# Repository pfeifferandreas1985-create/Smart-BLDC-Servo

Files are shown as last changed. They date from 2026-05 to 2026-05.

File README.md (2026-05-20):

# Smart BLDC Servo

Ein intelligenter, kompakter Closed-Loop BLDC-Servo-Controller basierend auf:
- **ESP32-C3 Super Mini**
- **SimpleFOC Mini v1.0 (DRV8313)**
- **AS5600 Magnet-Encoder** (I2C)
- **Feetech STS/SCS Emulation** (Half-Duplex 1-Wire UART, 1 Mbps)

Dieses Projekt ist die Weiterentwicklung des `SmartServoStepperV2` und ersetzt den lauten Stepper-Motor durch einen leisen, effizienten Brushless DC (BLDC) Motor (z. B. Gimbal Motoren).

---

## 🛠 Aktueller Entwicklungsstand

Die Hardware-Dokumentation (Schaltplan-Review, detaillierter Verdrahtungsplan, BOM) ist in den Markdown-Dateien `01` bis `06` im Hauptverzeichnis ausführlich dokumentiert.

### Open-Loop Test Tool (NEU!)
Im Verzeichnis `software/OpenLoopTest/` befindet sich das erste Testprogramm. Dieses Tool dient dazu, die grundlegende Hardware (ESP32-C3 + DRV8313 Treiber + BLDC Motor) sicher zu testen, **bevor** Encoder oder Feetech-Bus angeschlossen werden.

**Funktionen des Test-Tools:**
1. **WLAN-Web-Dashboard:** Steuerung des Motors über eine dunkle, professionelle Web-Oberfläche.
2. **Sicherer Open-Loop Modus:** Der Motor läuft im `velocity_openloop` Modus von SimpleFOC. Das Spannungs-Limit ist extrem konservativ gesetzt (2.5V), damit auch Motoren mit niedrigem Widerstand beim "Blockieren" nicht überhitzen.
3. **Hardware-Schutz:** Der Fehler-Pin (`nFLT`) des DRV8313 wird aktiv in Echtzeit vom ESP32-C3 überwacht. Bei Überstrom/Übertemperatur schaltet der ESP32 den Treiber sofort ab.
4. **Alignment:** Beim Start führt der Code automatisch ein elektrisches Alignment (2 rad/s) aus.

**Nutzung:**
1. Öffnen Sie `OpenLoopTest.ino` in der Arduino IDE und flashen Sie es auf den ESP32-C3 (Achtung: `USB CDC On Boot` muss auf `Enabled` stehen!).
2. Verbinden Sie sich mit dem ESP32 über Ihr Netzwerk.
3. Öffnen Sie `software/OpenLoopTest/gui/index.html` lokal im Browser.
4. Geben Sie die IP des ESP32 ein, klicken Sie auf *MOTOR AKTIVIEREN* und regeln Sie die Geschwindigkeit über den Slider.

---

## 🗂 Verzeichnisstruktur

- `software/` - Enthält Firmware (wie z.B. das OpenLoopTest-Tool)
- `software/OpenLoopTest/gui/` - Web-Dashboard für das Test-Tool
- `01_...` bis `06_...` - Ausführliche Baudokumentationen und Pin-Mappings
- `*.kicad_*` - Die KiCad 10.0 Projektdateien für das Hardware-Design

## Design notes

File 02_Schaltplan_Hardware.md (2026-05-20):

# 02. Hardware & Schaltplan

Dieses Dokument beschreibt die Verkabelung und die essenziellen Passivbauteile (Schutzschaltungen) für den stabilen Betrieb des BLDC 2208 80T am Simple FOC Mini v1.0.

## 1. Schutzschaltungen & Passivbauteile (Hardening)

Um einen zuverlässigen Dauerbetrieb zu gewährleisten und die Hardware vor Spannungsspitzen, Signalfehlern und Boot-Konflikten zu schützen, sind folgende Komponenten zwingend erforderlich:

### 1.1 VMOT Flyback- & Überspannungsschutz
BLDC Motoren können bei abruptem Abbremsen oder Blockieren als Generator wirken und hohe Spannungsspitzen ins Netz zurückspeisen.
*   **Bauteile:** 1x 1000 µF Elektrolytkondensator (Low ESR) + 1x 0.1 µF Keramikkondensator + 1x TVS-Diode **SMBJ24A** (bei 12V-24V) oder **SMBJ15A** (bei 12V) (alle parallel).
*   **Position:** Zwischen `VMOT` (Spannungseingang am Simple FOC Mini) und `GND`. So nah wie möglich an den Strom-Eingangspins des Treiber-Boards platzieren.

### 1.2 Glättung & MCU-Pufferung (Gegen Brownouts)
Verhindert, dass der ESP32-C3 durch Spannungseinbrüche während hoher Motorlasten abstürzt (Resets).
*   **Bauteile (5V Schiene):** 1x 100 µF Elko + 1x 47 µF Keramikkondensator (X7R, 1206, ≥16V) + 1x 100 nF Keramikkondensator.
*   **Position:** Direkt am 5V-Eingangspin des ESP32-C3 Super Mini.
*   **AS5600 Puffer:** 1x 10 µF Keramikkondensator nahe am VCC/GND-Pin des AS5600.
*   **Step-Down Puffer:** 1x 22 µF Keramikkondensator am Ausgang des MP1584EN.

### 1.3 I²C Pull-Up Widerstände (Für stabile 400 kHz)
Der AS5600 benötigt definierte HIGH-Pegel für saubere I2C-Kommunikation. Die internen Pull-Ups des ESP32-C3 sind zu schwach.
*   **Bauteile:** 2x 4.7 kΩ Widerstände.
*   **Position:** Einer von `SDA` an `3.3V` und einer von `SCL` an `3.3V`.

### 1.4 Boot-Safe Pull-Down am Enable Pin
Verhindert, dass der Motor unkontrolliert anläuft, während der ESP32-C3 bootet und die Pins noch im undefinierten Zustand (Floating) sind.
*   **Bauteil:** 1x 10 kΩ Widerstand.
*   **Position:** Zwischen `EN` (Enable-Pin des Simple FOC, Active-HIGH) und `GND`. Hält den Treiber deaktiviert, bis der ESP den Pin bewusst auf HIGH zieht.

### 1.5 nSLP & nRST Aktivierungs-Pull-Ups
*   **Problem:** Der DRV8313 besitzt interne 100kΩ Pull-Downs. Bleiben `nSLP` und `nRST` unbeschaltet, bleibt der Chip im Sleep/Reset-Zustand.
*   **Bauteile:** 2x 10 kΩ Widerstände.
*   **Position:** Von `nSLP` gegen `3.3V` und von `nRST` gegen `3.3V` (zieht die Pins dauerhaft HIGH und aktiviert den Treiber).

### 1.6 nFLT Fault-Feedback
*   **Bauteil:** 1x 10 kΩ Widerstand.
*   **Position:** Von `nFLT` (Fault-Ausgang des Simple FOC, Open-Drain) gegen `3.3V`. Der Pin wird an `GPIO 4` des ESP32-C3 angeschlossen, um Treiberfehler (Überstrom/Übertemperatur) in der Firmware abzufangen.

### 1.7 Split-Path Level Shifter für Feetech-Bus (1 Mbps Stabilität)
Verhindert Signalverrundungen und Frame-Fehler bei hohen Baudraten (1 Mbps), indem Sende- und Empfangspfad auf der 3.3V-Seite getrennt bleiben.
*   **Bauteile:** 1x BSS138 MOSFET (für TX) + 1x Spannungsteiler (4.7 kΩ Serie, 10 kΩ gegen GND, für RX) + 1x 2.2 kΩ Pull-Up (Terminierung).
*   **Position:**
    *   **TX-Pfad:** ESP32 TX (`GPIO 21`) → Gate/Source des BSS138 (Pegelwandlung 3.3V → 5V) → 5V Feetech Bus.
    *   **RX-Pfad:** 5V Feetech Bus → Spannungsteiler (4.7 kΩ / 10 kΩ) → ESP32 RX (`GPIO 20`).
    *   **Terminierung:** 2.2 kΩ Pull-Up von der 5V Feetech-Datenleitung gegen 5V.

---

## 2. Pin-Belegung & Architektur

### ESP32-C3 Super Mini Pinout:
*   **5V & GND:** Logikstromversorgung vom MP1584EN (mit 100µF + 47µF + 100nF Pufferung).
*   **3.3V & GND:** Sensorstromversorgung (AS5600) und Referenz für Level Shifter LV.
*   **GPIO 0 (PWM A):** Simple FOC IN1.
*   **GPIO 1 (PWM B):** Simple FOC IN2.
*   **GPIO 2 (PWM C):** Simple FOC IN3.
*   **GPIO 3 (EN):** Simple FOC Enable (mit 10kΩ Pull-Down an GND).
*   **GPIO 4 (nFLT):** Simple FOC Fault-Eingang (mit 10kΩ Pull-Up an 3.3V).
*   **GPIO 8 (SDA):** AS5600 SDA (mit 4.7kΩ Pull-Up an 3.3V).
*   **GPIO 9 (SCL):** AS5600 SCL (mit 4.7kΩ Pull-Up an 3.3V).
*   **GPIO 20 (RX):** Feetech Bus Empfang (über 4.7kΩ / 10kΩ Spannungsteiler von 5V Bus).
*   **GPIO 21 (TX):** Feetech Bus Senden (über unidirectional BSS138 Level Shifter auf 5V Bus).

### Stromversorgung (Power Routing)
1. **12V Hauptnetzteil:** Geht an Simple FOC Mini (VMOT/GND) und an den MP1584EN Step-Down (Eingang).
2. **MP1584EN Step-Down:** Wandelt 12V auf exakt **5.0V** um (Ausgang lokal mit 22µF gepuffert).
3. **5V Rail:** Versorgt den Level Shifter (HV-Referenz/Bus-Terminierung) und den 5V Eingang des ESP32-C3 Super Mini.
4. **3.3V Rail:** Vom ESP32-C3 3.3V Pin an den AS5600 Sensor und als Pull-Up-Referenz für nSLP, nRST und nFLT.

---

## 3. Logischer Schaltplan (Mermaid)

```mermaid
graph TD
    %% Stromversorgung
    PSU((12V Netzteil)) -->|12V| TVS[TVS SMBJ24A + 1000µF + 0.1µF]
    TVS -->|Gepufferte 12V| FOC[Simple FOC Mini]
    PSU -->|12V| BUCK[MP1584 Step-Down]
    BUCK -->|5V + 22µF| ESP_P_BUFF[100µF + 47µF + 100nF Puffer]
    ESP_P_BUFF -->|5V Logik| ESP_5V[ESP32-C3 5V Input]
    BUCK -->|5V| SHIFTER_HV[Terminierung 2.2kΩ an 5V Bus]
    
    %% Logikspannung
    ESP_5V -->|ESP Intern| ESP3V3(ESP32 3.3V Pin)
    ESP3V3 -->|3.3V| AS5600[AS5600 Encoder + 10µF]
    ESP3V3 -->|3.3V Pullups| PU_CTRL[Pull-Ups für nSLP, nRST & nFLT]
    
    %% Treiber Aktivierung & Fault
    PU_CTRL -->|10kΩ an 3.3V| FOC_nSLP[nSLP Pin]
    PU_CTRL -->|10kΩ an 3.3V| FOC_nRST[nRST Pin]
    FOC_nFLT[nFLT Pin] -->|Fault Signal| ESP_GPIO4[GPIO 4 - nFLT]
    PU_CTRL -->|10kΩ an 3.3V| ESP_GPIO4
    
    %% Boot-Safe Enable
    PD_EN[10kΩ Pull-Down an GND] --- ESP_GPIO3[GPIO 3 - EN]
    ESP_GPIO3 -->|Enable Signal| FOC
    
    %% PWM Signale
    ESP_GPIO0[GPIO 0] -->|PWM A| FOC
    ESP_GPIO1[GPIO 1] -->|PWM B| FOC
    ESP_GPIO2[GPIO 2] -->|PWM C| FOC
    
    %% I2C mit Pullups
    PU_I2C[2x 4.7kΩ an 3.3V] --- I2C_BUS[SDA/SCL Bus]
    ESP_GPIO8_9[GPIO 8/9] --> I2C_BUS
    I2C_BUS --> AS5600
    
    %% Motor
    FOC -->|3-Phasen AC| MOTOR((BLDC 2208 80T))
    AS5600 -.->|Magnetfeld| MOTOR
    
    %% Feetech Kommunikation Split-Path
    ESP_TX[GPIO 21 TX] -->|3.3V TX| LS_TX[BSS138 Level Shifter 3.3V-5V]
    LS_TX -->|5V TX| FT_BUS((5V Feetech Datenbus))
    FT_BUS -->|5V RX| DIV_RX[Spannungsteiler 4.7kΩ / 10kΩ]
    DIV_RX -->|3.3V RX| ESP_RX[GPIO 20 RX]
```

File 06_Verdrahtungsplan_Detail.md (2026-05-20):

# SmartBLDCServo – Detaillierter Verdrahtungsplan

> Dieser Plan beschreibt **jede einzelne Verbindung** zwischen den Modulen
> und erklärt exakt, wo jeder Widerstand, Kondensator und die Schutzdiode
> angeschlossen werden muss.

---

## Übersicht der Module (werden NICHT verändert)

| Ref  | Modul | Funktion |
|---|---|---|
| U1 | ESP32-C3 Super Mini | Mikrocontroller (MCU) |
| U2 | SimpleFOC Mini v1.0 | BLDC-Motortreiber (DRV8313) |
| U3 | MP1584EN Modul | Step-Down 12V → 5V |
| U4 | BOB-12009 (BSS138 Board) | Level Shifter 3.3V ↔ 5V |
| J1 | Schraubklemme 2-pol | 12V Eingang (VMOT + GND) |
| J2 | JST-XH 3-pol | Feetech-Bus (5V, DATA, GND) |
| J3 | JST-XH 4-pol | AS5600 Encoder (VCC,GND,SDA,SCL)|

---

## Übersicht aller passiven Bauteile

| Ref | Typ | Wert | Funktion | Angeschlossen zwischen |
|---|---|---|---|---|
| D1 | TVS-Diode | SMBJ15A | Überspannungsschutz 12V | VMOT (Kathode) ↔ GND (Anode) |
| C1 | Elko | 1000µF/25V | Bulk-Puffer 12V | VMOT ↔ GND |
| C2 | Keramik | 100nF/50V | HF-Entkopplung SimpleFOC | VMOT ↔ GND (direkt am U2) |
| C3 | Keramik | 10µF/25V | Eingangspuffer Buck-Converter | U3 IN+ ↔ U3 IN- |
| C4 | Keramik | 22µF/16V | Ausgangspuffer Buck-Converter | U3 OUT+ ↔ U3 OUT- |
| C5 | Elko | 100µF/10V | MCU-Puffer (Low-ESR) | U1 5V-Pin ↔ GND |
| C6 | Keramik | 47µF/16V | MCU-Puffer (X7R, 1206) | U1 5V-Pin ↔ GND |
| C7 | Keramik | 100nF | MCU HF-Filter | U1 5V-Pin ↔ GND |
| C8 | Keramik | 10µF/10V | AS5600 Entkopplung | J3 Pin1 (VCC) ↔ J3 Pin2 (GND) |
| R1 | 0603 | 10kΩ | EN Pull-Down (Treiber aus bei Boot)| U2 EN ↔ GND |
| R2 | 0603 | 10kΩ | nFLT Pull-Up (Fehlerleitung) | U2 nFLT ↔ 3.3V |
| R3 | 0603 | 10kΩ | nSLP Pull-Up (Treiber aktiv) | U2 nSLP ↔ 3.3V |
| R4 | 0603 | 10kΩ | nRST Pull-Up (kein Reset) | U2 nRST ↔ 3.3V |
| R5 | 0603 | 4.7kΩ | I2C SDA Pull-Up | SDA-Leitung ↔ 3.3V |
| R6 | 0603 | 4.7kΩ | I2C SCL Pull-Up | SCL-Leitung ↔ 3.3V |
| R7 | 0603 | 220Ω | TX Serienwiderstand (BOB-12009) | U1 GPIO21 ↔ U4 LV1 |
| R8 | 0603 | 4.7kΩ | RX Spannungsteiler (Serie) | TTL_1_Wire ↔ U1 GPIO20 |
| R9 | 0603 | 10kΩ | RX Spannungsteiler (Pull-Down) | U1 GPIO20 ↔ GND |
| R10 | 0603 | 2.2kΩ | Bus-Terminierung Pull-Up | TTL_1_Wire ↔ 5V |

---

## TEIL 1: STROMVERSORGUNG

### 1.1 – 12V Eingang und Schutz

```
       J1 (Schraubklemme)
       ┌──────┐
  12V──┤ Pin1 ├──┬──────────────────────────┬──── VMOT-Schiene
       │      │  │                          │
  GND──┤ Pin2 ├──┼──────────────────────────┼──── GND-Schiene
       └──────┘  │                          │
                 │                          │
           ┌─────┴─────┐            ┌───────┴───────┐
           │    D1      │            │     C1        │
           │  SMBJ15A   │            │  1000µF/25V   │
           │  (TVS)     │            │  (Elko)       │
           │            │            │               │
           │ Kathode=VMOT│           │  (+) = VMOT   │
           │ Anode=GND  │            │  (-) = GND    │
           └─────┬─────┘            └───────┬───────┘
                 │                          │
                 └──────────GND─────────────┘
```

**D1 (SMBJ15A):** Direkt parallel an J1. Kathode (Strich-Seite) an 12V/VMOT, Anode an GND.
Zweck: Kappt Spannungsspitzen von regenerativem Motorbremsen.

**C1 (1000µF/25V):** Direkt parallel an J1. Plus an VMOT, Minus an GND.
Zweck: Puffert große Stromspitzen beim Motorstart.

### 1.2 – SimpleFOC Mini Stromversorgung

```
  VMOT-Schiene ───────────────┬──── U2 VCC (Pin 14)
                              │
                         ┌────┴────┐
                         │   C2    │
                         │ 100nF   │
                         │ /50V    │
                         └────┬────┘
                              │
  GND-Schiene ────────────────┴──── U2 GND (Pin 15)
```

**C2 (100nF/50V):** So nah wie möglich an den VCC/GND-Pins des SimpleFOC Mini löten.
Zweck: Filtert hochfrequentes Rauschen des DRV8313 Treibers.

### 1.3 – Buck-Converter (MP1584EN) 12V → 5V

```
  VMOT ──┬──── U3 IN+          U3 OUT+ ──┬──── 5V-Schiene
         │                               │
    ┌────┴────┐                     ┌─────┴────┐
    │   C3    │                     │    C4    │
    │ 10µF    │                     │  22µF    │
    │ /25V    │                     │  /16V    │
    └────┬────┘                     └─────┬────┘
         │                               │
  GND ───┴──── U3 IN-          U3 OUT- ──┴──── GND
```

**C3 (10µF):** Direkt an IN+/IN- des MP1584EN Moduls.
**C4 (22µF):** Direkt an OUT+/OUT- des MP1584EN Moduls.

### 1.4 – ESP32-C3 Spannungsversorgung (5V-Eingang)

```
  5V-Schiene ──┬───────────────────────── U1 Pin "5V" (Pin 8)
               │
          ┌────┴────┐  ┌────┴────┐  ┌────┴────┐
          │   C5    │  │   C6    │  │   C7    │
          │ 100µF   │  │  47µF   │  │ 100nF   │
          │ Elko    │  │ Keramik │  │ Keramik │
          │ /10V    │  │ /16V    │  │         │
          └────┬────┘  └────┬────┘  └────┬────┘
               │            │            │
  GND ─────────┴────────────┴────────────┘
```

**C5, C6, C7:** Alle drei parallel, direkt am 5V-Pin des ESP32-C3 gegen GND.
Zweck: Verhindert MCU-Brownouts bei WiFi/BLE-Spitzenstrom.

### 1.5 – 3.3V Logik (vom ESP32 LDO)

```
  U1 Pin "3V3" (Pin 6) ───── 3.3V-Schiene
                               │
                               ├── R2, R3, R4 (Pull-Ups)
                               ├── R5, R6 (I2C Pull-Ups)
                               ├── U4 LV (BOB-12009 Low-Side)
                               └── J3 Pin1 (AS5600 VCC)
```

**WICHTIG:** Der 3.3V-Ausgang am SimpleFOC Mini (Pin 2) bleibt **UNBESCHALTET!**

---

## TEIL 2: ESP32-C3 ↔ SimpleFOC Mini (Motorsteuerung)

### 2.1 – PWM-Signale (direkte Verbindungen, KEINE Widerstände)

```
  U1 GPIO 0 ─────────────────── U2 IN1  (Phase A)
  U1 GPIO 1 ─────────────────── U2 IN2  (Phase B)
  U1 GPIO 2 ─────────────────── U2 IN3  (Phase C)
```

### 2.2 – Enable mit Pull-Down (R1)

```
  U1 GPIO 3 ──────┬──────────── U2 EN
                   │
              ┌────┴────┐
              │   R1    │
              │  10kΩ   │
              └────┬────┘
                   │
                  GND
```

**R1 (10kΩ):** Ein Bein an die Leitung GPIO3↔EN, anderes Bein an GND.
Zweck: Hält den Motortreiber während des ESP32-Bootvorgangs DEAKTIVIERT.

### 2.3 – Fault-Pin mit Pull-Up (R2)

```
                  3.3V
                   │
              ┌────┴────┐
              │   R2    │
              │  10kΩ   │
              └────┬────┘
                   │
  U1 GPIO 4 ──────┴──────────── U2 nFLT
```

**R2 (10kΩ):** Ein Bein an die Leitung GPIO4↔nFLT, anderes Bein an 3.3V.
Zweck: nFLT ist Open-Drain. Pull-Up hält Signal auf HIGH wenn kein Fehler vorliegt.

### 2.4 – Sleep und Reset permanent aktiv (R3, R4)

```
                  3.3V                3.3V
                   │                   │
              ┌────┴────┐         ┌────┴────┐
              │   R3    │         │   R4    │
              │  10kΩ   │         │  10kΩ   │
              └────┬────┘         └────┬────┘
                   │                   │
              U2 nSLP              U2 nRST
```

**R3 (10kΩ):** Von U2 nSLP (Pin 8) nach 3.3V. Treiber bleibt aus Sleep-Modus.
**R4 (10kΩ):** Von U2 nRST (Pin 6) nach 3.3V. Treiber bleibt aus Reset.

> **ACHTUNG:** nSLP und nRST haben interne 100kΩ Pull-Downs im DRV8313!
> Ohne diese externen 10kΩ Pull-Ups bleibt der Treiber im Schlaf/Reset!

---

## TEIL 3: ESP32-C3 ↔ AS5600 Encoder (I2C über J3)

### 3.1 – Encoder-Steckerbelegung (J3, JST-XH 4-pol)

```
       J3 (4-pol Buchse)
       ┌──────────┐
  VCC──┤  Pin 1   ├──── 3.3V (vom ESP32 LDO)
  GND──┤  Pin 2   ├──── GND
  SDA──┤  Pin 3   ├──── U1 GPIO 8
  SCL──┤  Pin 4   ├──── U1 GPIO 9
       └──────────┘
```

### 3.2 – I2C Pull-Ups (R5, R6) und Entkopplung (C8)

```
         3.3V         3.3V
          │             │
     ┌────┴────┐   ┌────┴────┐
     │   R5    │   │   R6    │
     │  4.7kΩ  │   │  4.7kΩ  │
     └────┬────┘   └────┬────┘
          │             │
  GPIO8 ──┴── SDA       │
                        │
  GPIO9 ────────────────┴── SCL

  J3 Pin1 (VCC) ──┬──── 3.3V
                   │
              ┌────┴────┐
              │   C8    │
              │  10µF   │
              └────┬────┘
                   │
  J3 Pin2 (GND) ──┴──── GND
```

**R5 (4.7kΩ):** Ein Bein an SDA-Leitung (GPIO8 ↔ J3 Pin3), anderes an 3.3V.
**R6 (4.7kΩ):** Ein Bein an SCL-Leitung (GPIO9 ↔ J3 Pin4), anderes an 3.3V.
**C8 (10µF):** Direkt an J3 zwischen Pin1 (VCC) und Pin2 (GND). So nah wie möglich am Stecker.

---

## TEIL 4: FEETECH-BUS (1 Mbps, Split-Path über BOB-12009)

### 4.1 – Gesamtübersicht

```
  3.3V-Seite (ESP32)              5V-Seite (Bus)
  ══════════════════              ═══════════════

  GPIO21 (TX)──[R7 220Ω]──U4 LV1 ── U4 HV1──┬── TTL_1_Wire
                                              │
  GPIO20 (RX)──────────────[R8 4.7kΩ]────────┤
       │                                      │
      [R9 10kΩ]                          [R10 2.2kΩ]
       │                                      │
      GND                                    5V

  U4 LV  = 3.3V
  U4 HV  = 5V
  U4 GND = GND
```

### 4.2 – TX-Pfad: ESP32 → Bus (über BOB-12009 Kanal 1)

```
  U1 GPIO 21 ──[R7 220Ω]──── U4 LV1
                              U4 HV1 ──── TTL_1_Wire (Datenleitung)
```

**R7 (220Ω):** In Serie zwischen GPIO21 und dem LV1-Pin des BOB-12009.
Zweck: Begrenzt Strom und reduziert Überschwinger an der steigenden Flanke.

### 4.3 – RX-Pfad: Bus → ESP32 (Spannungsteiler, NICHT über BOB-12009)

```
  TTL_1_Wire (5V Bus) ──[R8 4.7kΩ]──┬──── U1 GPIO 20
                                      │
                                 [R9 10kΩ]
                                      │
                                     GND
```

**R8 (4.7kΩ):** Von TTL_1_Wire Busleitung zum GPIO20 (in Serie).
**R9 (10kΩ):** Von GPIO20 nach GND (Pull-Down).

Ergebnis: 5V × (10k / (4.7k + 10k)) = **3.4V** → sicher für den 3.3V-toleranten GPIO.
Zweck: Schneller, passiver Pegelwandler ohne MOSFET-Verzögerung für RX.

### 4.4 – Bus-Terminierung (R10)

```
  TTL_1_Wire ──[R10 2.2kΩ]──── 5V (von MP1584EN)
```

**R10 (2.2kΩ):** Direkt am Feetech-Stecker J2, von der Datenleitung nach 5V.
Zweck: Zieht die Busleitung schnell auf 5V zurück (scharfe steigende Flanken bei 1 Mbps).

### 4.5 – BOB-12009 Versorgung und unbeschaltete Pins

```
  U4 LV  ──── 3.3V (vom ESP32)
  U4 HV  ──── 5V (vom MP1584EN)
  U4 GND ──── GND
  U4 LV2 ──── unbeschaltet (offen)
  U4 LV3 ──── unbeschaltet (offen)
  U4 LV4 ──── unbeschaltet (offen)
  U4 HV2 ──── unbeschaltet (offen)
  U4 HV3 ──── unbeschaltet (offen)
  U4 HV4 ──── unbeschaltet (offen)
```

### 4.6 – Feetech-Stecker (J2, JST-XH 3-pol)

```
       J2 (3-pol Buchse)
       ┌──────────┐
   5V──┤  Pin 1   ├──── 5V (Versorgung für externe Servos)
  DATA──┤  Pin 2   ├──── TTL_1_Wire (Datenleitung)
  GND──┤  Pin 3   ├──── GND
       └──────────┘
```

---

## TEIL 5: MOTOR-AUSGÄNGE (SimpleFOC Mini → Motor)

Die drei Phasenausgänge des SimpleFOC Mini gehen direkt zum BLDC-Motor:

```
  U2 OUT1 (Pin 13) ──── Motor Phase A
  U2 OUT2 (Pin 12) ──── Motor Phase B
  U2 OUT3 (Pin 11) ──── Motor Phase C
```

Keine zusätzlichen Bauteile notwendig. Die Motorleitungen sollten möglichst
kurz und mit breiten Leiterbahnen (≥1.5mm) geführt werden.

---

## ZUSAMMENFASSUNG: Alle Verbindungen auf einen Blick

### ESP32-C3 Pin-Belegung (U1)

| ESP32 Pin | Richtung | Verbindung zu | Passive Bauteile |
|---|---|---|---|
| 5V | Eingang  | MP1584EN OUT+ | C5 (100µF), C6 (47µF), C7 (100nF) → GND |
| 3V3 | Ausgang  | 3.3V-Schiene | – |
| GND | – | System-GND | – |
| GPIO 0 | Ausgang  | U2 IN1 | – |
| GPIO 1 | Ausgang  | U2 IN2 | – |
| GPIO 2 | Ausgang  | U2 IN3 | – |
| GPIO 3 | Ausgang  | U2 EN | R1 (10kΩ) → GND |
| GPIO 4 | Eingang  | U2 nFLT | R2 (10kΩ) → 3.3V |
| GPIO 8 | Bidir. | J3 Pin3 (SDA) | R5 (4.7kΩ) → 3.3V |
| GPIO 9 | Ausgang  | J3 Pin4 (SCL) | R6 (4.7kΩ) → 3.3V |
| GPIO 20 | Eingang  | TTL_1_Wire via R8 | R8 (4.7kΩ Serie), R9 (10kΩ) → GND |
| GPIO 21 | Ausgang  | U4 LV1 via R7 | R7 (220Ω Serie) |

### SimpleFOC Mini Pin-Belegung (U2)

| U2 Pin | Verbindung zu | Passive Bauteile |
|---|---|---|
| VCC (14)  | VMOT (12V-Schiene) | C2 (100nF) → GND |
| GND (15)  | System-GND | – |
| GND1 (1)  | System-GND | – |
| GND2 (4)  | System-GND | – |
| IN1 (3) | U1 GPIO 0 | – |
| IN2 (5) | U1 GPIO 1 | – |
| IN3 (7) | U1 GPIO 2 | – |
| EN (9) | U1 GPIO 3 | R1 (10kΩ) → GND |
| nRST (6)  | – | R4 (10kΩ) → 3.3V |
| nSLP (8)  | – | R3 (10kΩ) → 3.3V |
| nFLT (10) | U1 GPIO 4 | R2 (10kΩ) → 3.3V |
| 3.3V (2)  | **UNBESCHALTET!** | – |
| OUT1 (13) | Motor Phase A | – |
| OUT2 (12) | Motor Phase B | – |
| OUT3 (11) | Motor Phase C | – |

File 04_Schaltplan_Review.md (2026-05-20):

# 04. Schaltplan- & Schutzschaltungs-Review (SmartBLDCServo)

Dieses Dokument enthält das technische Review des Schaltplans und der Schutzschaltungen für das Projekt **SmartBLDCServo** auf Basis des Gimbal-Motors (2208 80T) und des **SimpleFOC Mini v1.0**-Treibers. Die Schaltung wurde im Vergleich zu den Freigabestandards des Vorgängerprojekts **SmartServoStepperV2** geprüft.

---

## 1. Kritische Fehler (Müssen vor dem PCB-Layout behoben werden)

### 1.1 Unbeschaltete nSLP und nRST Pins am SimpleFOC Mini (Fehlende Aktivierung)
*   **Problem:** Der DRV8313-Treiberchip auf dem SimpleFOC Mini besitzt interne **100 kΩ Pull-Down-Widerstände** an den Steuereingängen. Die Pins `nSLP` (Sleep, Pin 8) und `nRST` (Reset, Pin 6) sind **Active-LOW**. Wenn diese Pins in der Schaltung unbeschaltet (floating) bleiben, zieht der Chip sie auf GND und verbleibt dauerhaft im Sleep- und Reset-Zustand. Der Treiber wird keine PWM-Signale annehmen und der Motor bleibt stromlos.
*   **Lösung:** Verbinden Sie sowohl `nSLP` als auch `nRST` mit **3.3V** (entweder direkt oder jeweils über einen **10 kΩ Pull-Up-Widerstand**). Dadurch wird der Treiber permanent aktiviert.
*   **Hinweis:** Der `3.3V` Pin auf dem SimpleFOC Mini Header (Pin 2) ist der Ausgang eines chipinternen LDO-Reglers (max. 10 mA). Sie können die Pins `nSLP`/`nRST` entweder mit diesem Pin 2 oder direkt mit der 3.3V-Schiene des ESP32-C3 verbinden (empfohlen, da stabiler).

### 1.2 Fehlende Glättungs- und Pufferkondensatoren an den Logikschienen (5V & 3.3V)
*   **Problem:** In der aktuellen BOM und dem Verdrahtungsplan fehlen jegliche Abblockkondensatoren an den Spannungsreglern und MCU-Eingängen. BLDC-Motoren erzeugen durch das schnelle Schalten der Phasen starke Störungen (Rippel) auf der Versorgungsspannung. Ohne Pufferung wird der ESP32-C3 beim Anlauf des Motors durch Spannungsabfälle (Brownouts) abstürzen oder unvorhersehbares Verhalten zeigen.
*   **Lösung (analog zum SmartServoStepperV2-Standard):**
    *   **MP1584EN Ausgang (5V Rail):** Platzieren Sie mindestens einen **22 µF Keramikkondensator** (X7R, 1206) direkt am Ausgang des Reglers.
    *   **ESP32-C3 5V Input:** Platzieren Sie eine Kombination aus **100 µF Elko** + **47 µF Keramikkondensator** (X7R, 1206, ≥16V) + **100 nF Keramikkondensator** so nah wie möglich am 5V-Pin des ESP32.
    *   **AS5600 Sensor (3.3V Rail):** Platzieren Sie einen **10 µF Keramikkondensator** direkt an den VCC- und GND-Pins des Sensors.

---

## 2. Dringende Empfehlungen zur Stabilitäts-Optimierung

### 2.1 Feetech-Bus Level Shifter: Bidirektional vs. Unidirektionaler Split-Pfad (1 Mbps Stabilität)
*   **Problem:** Die Schaltung sieht den kombinierten 1-Wire UART mit dem bidirektionalen Level Shifter BSS138 (`LV1` zu `HV1` mit 220 Ω Schutzwiderstand) vor. Bei der hohen Übertragungsrate des Feetech-Busses von **1 Mbps** führt die hohe Gate-Kapazität und der langsame Pull-Up-Übergang des BSS138 zu einer starken Verrundung der Signalflanken. Dies führt im Betrieb häufig zu Frame-Fehlern.
*   **Lösung aus SmartServoStepperV2 V1.6:**
    Nutzen Sie die freien GPIOs des ESP32-C3 und teilen Sie den Pfad in einen unidirektionalen TX-Pfad und einen RX-Spannungsteiler-Pfad auf. Diese werden erst auf der 5V-Seite zusammengeführt:
    1.  **TX-Pfad:** ESP32 TX (`GPIO 21`) → Gate/Source des BSS138 (Pegelwandlung 3.3V → 5V) → 5V-Bus.
    2.  **RX-Pfad:** 5V-Bus → Spannungsteiler (**4.7 kΩ** in Serie, **10 kΩ** gegen GND) → ESP32 RX (`GPIO 20`).
    3.  **Terminierung:** Ein starker **2.2 kΩ Pull-Up-Widerstand** vom 5V-Bus gegen 5V sorgt für scharfe Signalflanken.
*   **Vorteil:** Durch diese Trennung muss der Level Shifter nur unidirektional arbeiten, was die Signalqualität bei 1 Mbps massiv erhöht. Da beim ESP32-C3 die GPIOs 4, 5, 6, 7 und 10 ungenutzt sind, steht dieser Änderung nichts im Weg.

### 2.2 Fehlender TVS-Schutz am VMOT-Eingang (Flyback-Überspannungsschutz)
*   **Problem:** Der 1000 µF Elko schützt vor kurzzeitigen Rückspeisungen, fängt jedoch keine hochenergetischen transienten Überspannungen ab, die entstehen, wenn der Motor blockiert oder abrupt gestoppt wird. Diese Spannungsspitzen können den SimpleFOC Mini sowie den MP1584 Buck-Converter zerstören.
*   **Lösung:** Schalten Sie eine **TVS-Diode** (Transienten-Absorptionsdiode) vom Typ **SMBJ24A** (bei 12V-24V Betrieb) oder **SMBJ15A** (bei reinem 12V Betrieb) parallel zum 1000 µF Kondensator direkt an den VMOT-Eingang (Kathode an VMOT, Anode an GND).

---

## 3. Optionale Komfort-Features

### 3.1 Nutzung des Fehler-Pins (nFLT)
*   **Vorteil:** Der SimpleFOC Mini hat einen Open-Drain Ausgang `nFLT` (Pin 10), der im Fehlerfall (Übertemperatur, Überstrom am DRV8313) auf LOW gezogen wird.
*   **Empfehlung:** Verbinden Sie `nFLT` über einen **10 kΩ Pull-Up-Widerstand** gegen 3.3V mit einem freien ESP32 GPIO (z.B. `GPIO 4`). Ihre Firmware kann dadurch Fehler sofort erkennen, den Motor stoppen und eine Fehlermeldung über den Bus senden.

---

## 4. Korrekt und sinnvoll umgesetzte Schaltungsteile (Best Practice)

*   ✔ **Boot-Safe Enable State:** Der **10 kΩ Pull-Down-Widerstand** am `EN`-Pin (Pin 9) des SimpleFOC Mini ist absolut korrekt. Da der Treiber-Enable-Pin Active-HIGH is, hält dieser Widerstand den Motor beim Booten der MCU sicher stromlos, solange die GPIOs schwimmen.
*   ✔ **I2C Pull-Ups:** Die beiden **4.7 kΩ Pull-Up-Widerstände** an SDA/SCL gegen 3.3V sind für den stabilen Betrieb des AS5600 im 400 kHz Fast Mode ideal dimensioniert.
*   ✔ **Softwareseitige Sicherheitslimits:** Die Reduzierung des Spannungslimits im Code (`driver.voltage_limit = 6.0;` bei `driver.voltage_power_supply = 12.0;`) ist sehr sinnvoll für Gimbal-Motoren, da diese einen hohen Phasenwiderstand aufweisen und bei vollen 12V schnell überhitzen würden.

---

## 5. Empfohlenes optimiertes Pin-Mapping

Unter Berücksichtigung der Optimierungen ergibt sich folgende Empfehlung für die Pin-Belegung des ESP32-C3:

| Pin | Funktion | Richtung | Anbindung / Hardware-Schutz |
| :--- | :--- | :--- | :--- |
| **GPIO 0** | PWM Phase A | Ausgang | Direkt an `IN1` des SimpleFOC |
| **GPIO 1** | PWM Phase B | Ausgang | Direkt an `IN2` des SimpleFOC |
| **GPIO 2** | PWM Phase C | Ausgang | Direkt an `IN3` des SimpleFOC |
| **GPIO 3** | Driver Enable | Ausgang | An `EN` des SimpleFOC (mit 10 kΩ Pull-Down an GND) |
| **GPIO 4** | Driver Fault (nFLT)| Eingang | An `nFLT` des SimpleFOC (mit 10 kΩ Pull-Up an 3.3V) |
| **GPIO 8** | I2C SDA | Bidirektional | An AS5600 SDA (mit 4.7 kΩ Pull-Up an 3.3V) |
| **GPIO 9** | I2C SCL | Ausgang | An AS5600 SCL (mit 4.7 kΩ Pull-Up an 3.3V) |
| **GPIO 20**| Feetech Bus RX | Eingang | Über 5V→3.3V Spannungsteiler (4.7 kΩ / 10 kΩ) an den Bus |
| **GPIO 21**| Feetech Bus TX | Ausgang | Über Level Shifter (BSS138) an den 5V-Bus |

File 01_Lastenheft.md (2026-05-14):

# Projekt: Smart BLDC Servo – Lastenheft

## 1. Zielbeschreibung
Entwicklung eines intelligenten, Closed-Loop gesteuerten BLDC-Servos auf Basis eines Gimbal-Motors (2208 80T) und ESP32-C3 Super Mini. Das System integriert einen Simple FOC Mini v1.0 Treiber und einen AS5600 Encoder für präzises Positions-, Geschwindigkeits-, und Drehmoment-Feedback mittels Field Oriented Control (FOC).
Es soll sich am Datenbus exakt wie ein Feetech STS/SCS Servomotor ansprechen lassen.

## 2. Hardware-Spezifikationen
*   **Zentrale Logik:** ESP32-C3 Super Mini.
*   **Motor:** BLDC 2208 80T (Gimbal Motor, typischerweise 11 Polpaare).
*   **Treiber:** Simple FOC Mini v1.0 (Unterstützt bis 24V, max 5A).
*   **Sensorik:** AS5600 absoluter Magnet-Encoder (12-Bit, I2C, 4096 Schritte).
*   **Bus-Interface:** 5V Level Shifter + 220Ω Widerstand für 5V Half-Duplex Kommunikation (Feetech-Stil).
*   **Power Management:** Hauptspannung (z.B. 12V); MP1584 Step-Down Converter auf 5V für den ESP32-C3 und die High-Side des Level Shifters.

## 3. Betriebsmodi (Control Modes)
Das System nutzt die SimpleFOC Bibliothek und unterstützt folgende Modi:
1.  **Position Control:** Präzise Anfahrt der Zielposition (Winkel).
2.  **Velocity Control:** Konstante Drehzahl.
3.  **Torque Control (Voltage-based):** Direkte Vorgabe der Spannung/des Drehmoments.

## 4. Software Features & Fail-Safe
*   **SimpleFOC Integration:** Ruckelfreie und leise Steuerung mittels Sinus-Kommutierung.
*   **Closed-Loop:** Laufende Positionskorrektur.
*   **Boot-Safe State:** Pull-Down Widerstand am Enable-Pin, um den Motor während des Bootvorgangs stromlos zu halten.
*   **Kommunikation:** UART über Level-Shifter (Half-Duplex) zum Auslesen und Setzen von Zielwerten.

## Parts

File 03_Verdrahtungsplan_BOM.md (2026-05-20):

# Verdrahtungsplan & Bill of Materials (BOM)
**Projekt: Smart BLDC Servo (2208 80T)**

Dieses Dokument enthält den detaillierten Verdrahtungsplan, die exakten Pin-Belegungen aller Module, die Liste der Schutzbeschaltungen sowie die vollständige Stückliste (BOM) unter Einbeziehung aller Schutzschaltungen für maximalen Betriebsschutz.

---

## 1. Bill of Materials (BOM) - Stückliste

| Menge | Bauteil / Modul | Spezifikation / Wert | Funktion / Einsatzzweck |
| :--- | :--- | :--- | :--- |
| 1x | **ESP32-C3 Super Mini** | 3.3V Logik, WLAN/BT | Haupt-Mikrocontroller, Regelkreis & Kommunikation |
| 1x | **Simple FOC Mini v1.0** | 3-PWM, max 24V/5A | BLDC Motortreiber für FOC Steuerung |
| 1x | **Gimbal Motor 2208** | 80T, typisch 11 Polpaare | Der BLDC Motor selbst (Aktor) |
| 1x | **AS5600 Encoder** | I2C, 12-Bit Auflösung | Absoluter Magnet-Encoder für Winkelmessung |
| 1x | **MP1584EN Step-Down** | Einstellbar (auf 5.0V justieren) | Wandelt 12V Motorenspannung auf 5V für die Logik |
| 1x | **BSS138 Transistor** | N-Channel MOSFET | Unidirektionaler Level Shifter für den TX-Pfad |
| 1x | **TVS-Diode** | **SMBJ24A** (oder SMBJ15A bei 12V) | Transientenschutz (Flyback-Schutz) am VMOT-Eingang |
| 1x | Elektrolytkondensator | **1000 µF / 25V** (Low ESR) | VMOT Hauptpufferung am Simple FOC Mini |
| 1x | Elektrolytkondensator | **100 µF / 10V** (oder höher) | MCU 5V-Eingangspufferung gegen Spannungseinbrüche |
| 1x | Keramikkondensator | **47 µF** (X7R, 1206, ≥10V) | MCU 5V-Eingang Logik-Entkopplung |
| 1x | Keramikkondensator | **22 µF** (X7R, 0805/1206) | MP1584EN Buck-Converter Ausgangsglättung |
| 2x | Keramikkondensator | **10 µF** | 1x nahe AS5600 VCC, 1x nahe MP1584EN Eingang |
| 2x | Keramikkondensator | **0.1 µF** | 1x parallel zu VMOT Elko, 1x direkt am ESP32 5V-Pin |
| 2x | Widerstand | **4.7 kΩ** | I2C Fast-Mode Pull-Ups (SDA/SCL) an 3.3V & RX-Teiler (Serie) |
| 4x | Widerstand | **10 kΩ** | 1x EN Pull-down, 2x nSLP/nRST Pull-ups, 1x nFLT Pull-up & RX-Teiler (GND) |
| 1x | Widerstand | **2.2 kΩ** | Feetech 5V-Bus Terminierung (Pull-up gegen 5V) |
| 1x | Magnet | Diametral magnetisiert | Für den AS5600-Sensor (auf Motorwelle kleben) |

---

## 2. Modul-Verdrahtungstabellen (Pinout)

### ⚡ Stromversorgung & Pufferkondensatoren (Power Grid)
| Quelle / Modul | Pin | Ziel / Modul | Pin | Anmerkung |
| :--- | :--- | :--- | :--- | :--- |
| **12V Netzteil** | `V+ (12V)` | Simple FOC Mini | `VMOT` | Hauptleitung. `SMBJ24A` (TVS), `1000µF` (Elko) & `0.1µF` (Keramik) parallel gegen GND schalten! |
| **12V Netzteil** | `GND` | Simple FOC Mini | `GND` | Leistungs-Masse |
| **12V Netzteil** | `V+ (12V)` | MP1584EN | `IN+` | Eingang für Step-Down (lokal mit `10µF` puffern) |
| **12V Netzteil** | `GND` | MP1584EN | `IN-` | Masse für Step-Down |
| MP1584EN | `OUT+ (5V)` | ESP32-C3 | `5V` | ESP32 5V-Pin (lokal mit `100µF` + `47µF` + `100nF` gegen GND puffern!). `22µF` direkt an MP1584EN Ausgang. |
| MP1584EN | `OUT+ (5V)` | Feetech Bus | `5V (Red)` | Spannungsversorgung für externe Busteilnehmer (falls benötigt) |
| MP1584EN | `OUT- (GND)`| System GND | `GND` | Sternpunkt-Masse. Alle GNDs (ESP, Shifter, AS5600) verbinden. |

### 🧠 ESP32-C3 Super Mini -> Simple FOC Mini (Motorsteuerung & Schutz)
| ESP32-C3 Pin | Funktion | Simple FOC Mini Pin | Anmerkung / Externe Beschaltung |
| :--- | :--- | :--- | :--- |
| `GPIO 0` | PWM A | `IN1` | Phase A Steuerung |
| `GPIO 1` | PWM B | `IN2` | Phase B Steuerung |
| `GPIO 2` | PWM C | `IN3` | Phase C Steuerung |
| `GPIO 3` | Enable | `EN` | Schaltet den Treiber an/aus (**10 kΩ Pull-Down** gegen GND zwingend!) |
| `GPIO 4` | Fault | `nFLT` | Fehler-Feedback (**10 kΩ Pull-Up** gegen 3.3V zwingend!) |
| - | - | `nSLP` | Schlafeingang (über **10 kΩ Pull-Up** an 3.3V daueraktiv geschaltet) |
| - | - | `nRST` | Reseteingang (über **10 kΩ Pull-Up** an 3.3V daueraktiv geschaltet) |
| `3.3V` (Ausgang)| Logik-Power | `3.3V` (Pin 2) | **Unbeschaltet lassen!** Interner LDO hat nur 10mA. |
| `GND` | Masse | `GND` | Signal-Masse |

### 👁️ ESP32-C3 Super Mini -> AS5600 (Sensor)
| ESP32-C3 Pin | Funktion | AS5600 Pin | Anmerkung |
| :--- | :--- | :--- | :--- |
| `3.3V` (Ausgang)| Logik-Power | `VCC` | Der AS5600 läuft auf 3.3V (lokal mit `10µF` entkoppeln) |
| `GND` | Masse | `GND` | Masse |
| `GPIO 8` | I2C SDA | `SDA` | Datenleitung (**4.7 kΩ Pull-Up** an 3.3V) |
| `GPIO 9` | I2C SCL | `SCL` | Clock-Leitung (**4.7 kΩ Pull-Up** an 3.3V) |

### 🔌 ESP32-C3 Super Mini -> Feetech Bus (Split-Path Level Shifter)
| ESP32-C3 Pin | Funktion | Signalweg / Level Shifter | Anmerkung / Externe Beschaltung |
| :--- | :--- | :--- | :--- |
| `GPIO 21` | UART TX | → BSS138 Source | **TX-Pfad (3.3V → 5V):** BSS138 Gate an 3.3V. BSS138 Drain geht an die 5V Bus-Datenleitung. |
| `GPIO 20` | UART RX | ← Spannungsteiler | **RX-Pfad (5V → 3.3V):** Von der 5V Bus-Datenleitung über 4.7 kΩ in Serie an GPIO 20. GPIO 20 über 10 kΩ gegen GND schalten. |
| `3.3V` (Ausgang)| Logik-Referenz| BSS138 Gate / VIO | 3.3V Referenzspannung |
| `GND` | Masse | GND | Gemeinsame Masse |

### 🌐 Physische Bus-Terminierung (Am Ausgangsstecker)
| Bus-Leitung | Pin | Beschaltung | Anmerkung |
| :--- | :--- | :--- | :--- |
| `5V (VCC)` | Pin 1 | - | Stromversorgung des Busses |
| `DATA (5V)` | Pin 2 | **2.2 kΩ Pull-Up** gegen 5V | **Bus-Terminierung:** Zwingend erforderlich für scharfe Signalflanken bei 1 Mbps |
| `GND` | Pin 3 | - | Masse-Referenz |

---

## 3. Schutzbeschaltung (Detaillierte Einbauorte)

1. **VMOT Flyback Puffer & TVS (am Simple FOC Mini):**
   * **Bauteile:** `1000 µF / 25V` Low-ESR Elko + `0.1 µF` Keramik + TVS-Diode `SMBJ24A` (parallel).
   * **Einbauort:** Unmittelbar zwischen den Schraubklemmen/Pads von `VMOT` und `GND` des Simple FOC Mini.
   * **Warum?** Verhindert induktive Spannungsspitzen durch die Generatorwirkung des BLDC-Motors bei schnellen Richtungswechseln.

2. **MCU-Glättung (ESP32-C3 Brownout-Schutz):**
   * **Bauteile:** `100 µF` Elko + `47 µF` Keramikkondensator (X7R, 1206) + `100 nF` Keramik (parallel).
   * **Einbauort:** Direkt am `5V`-Pin und dem nahen `GND`-Pin des ESP32-C3 Super Mini.
   * **Warum?** Filtert hochfrequente Störsignale des Treibers heraus und puffert Stromspitzen des ESP32-C3 beim Senden über WLAN oder Bus.

3. **I2C Fast-Mode Pull-Ups (für den AS5600):**
   * **Bauteile:** 2x `4.7 kΩ` Widerstände.
   * **Einbauort:** Einer von `GPIO 8 (SDA)` an `3.3V`, einer von `GPIO 9 (SCL)` an `3.3V`.
   * **Warum?** Die internen Pull-Ups des ESP32-C3 sind zu schwach für 400kHz. Ohne diese Widerstände kommt es zu Sensor-Aussetzern (Rauschen).

4. **Boot-Safe Pull-Down (am Simple FOC Mini):**
   * **Bauteil:** 1x `10 kΩ` Widerstand.
   * **Einbauort:** Zwischen `EN` Pin (Pin 9) des Simple FOC Mini und `GND`.
   * **Warum?** Hält den Motor beim Booten oder Flashen der MCU sicher ausgeschaltet, da der Treiber-Pin Active-HIGH ist und der ESP32-Pin beim Start floaten kann.

5. **nSLP/nRST Treiber-Aktivierung:**
   * **Bauteile:** 2x `10 kΩ` Widerstände.
   * **Einbauort:** Jeweils einer von `nSLP` (Pin 8) und `nRST` (Pin 6) des Simple FOC Mini gegen `3.3V`.
   * **Warum?** Der DRV8313 schaltet sich ohne dieses HIGH-Signal dauerhaft stumm (interner Pull-down).

6. **nFLT Überlastungsschutz:**
   * **Bauteil:** 1x `10 kΩ` Widerstand.
   * **Einbauort:** Zwischen `nFLT` (Pin 10) des Simple FOC Mini und `3.3V`. Zudem direkte Verbindung an `GPIO 4` des ESP32.
   * **Warum?** Hält das Fehlersignal auf HIGH. Zieht der Treiber bei Überlast `nFLT` auf LOW, schaltet die Firmware sofort den Motor ab.

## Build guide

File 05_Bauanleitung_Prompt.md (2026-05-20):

# 05. Bauanleitung & Detail-Prompt für Schaltplanerstellung

Dieses Dokument enthält einen präzisen, detaillierten Prompt, der das gesamte Schaltungsdesign und die Verdrahtung so beschreibt, dass eine externe Person (oder eine KI wie Claude/GPT) den Schaltplan und das PCB-Layout fehlerfrei und exakt nachbauen kann.

---

## Kopierbarer Prompt für Schaltplan und Layout (Deutsch)

```text
Erstelle einen vollständigen, professionellen Schaltplan für einen intelligenten Closed-Loop BLDC-Servomotor (Projektname: SmartBLDCServo). Die Schaltung basiert auf einem ESP32-C3 Super Mini Mikrocontroller, einem Simple FOC Mini v1.0 Treiberboard (DRV8313), einem AS5600 Magnetsensor (I2C) und einem 1 Mbps Feetech-kompatiblen Half-Duplex Eindraht-Bus.

Befolge exakt die folgenden Verdrahtungsvorgaben und Schutzbeschaltungen:

### 1. STROMVERSORGUNG & SPANNUNGSGLÄTTUNG (POWER GRID)
- HAUPTVERSORGUNG (12V):
  * Eingangsklemmen für 12V Hauptspannung (VMOT) und GND.
  * Schalte direkt parallel am 12V-Eingang des Simple FOC Mini folgende Bauteile zum Schutz vor Flyback-Spannungsspitzen:
    1. Eine TVS-Diode vom Typ SMBJ24A (oder SMBJ15A) parallel (Kathode an VMOT, Anode an GND).
    2. Einen 1000 µF / 25V Low-ESR Elektrolytkondensator.
    3. Einen 0.1 µF (100 nF) Keramikkondensator.

- DEZENTRALE SPANNUNGSREGELUNG (12V auf 5V):
  * Nutze einen MP1584EN Buck-Converter.
  * Eingang: VMOT (12V) und GND (lokal gepuffert mit einem 10 µF Keramikkondensator).
  * Ausgang: Auf 5.0V einstellen. Schalte einen 22 µF Keramikkondensator direkt parallel an den 5V-Ausgang.
  * Die 5V-Schiene versorgt den ESP32-C3 "5V" Pin und die High-Side (HV) des Feetech-Busses.

- MCU-GLÄTTUNG & ENTSTATTUNG (ESP32-C3 5V Input):
  * Schalte direkt am 5V-Eingangspin des ESP32-C3 Super Mini eine Kondensatorbatterie gegen GND, um MCU-Brownouts zu verhindern:
    1. Einen 100 µF Elektrolytkondensator (Low ESR).
    2. Einen 47 µF Keramikkondensator (X7R, Bauform 1206, Nennspannung ≥16V).
    3. Einen 100 nF Keramikkondensator zur HF-Filterung.

- LOGIKSPANNUNG (3.3V):
  * Die 3.3V-Logikspannung wird vom internen LDO-Regler des ESP32-C3 erzeugt (3.3V Pin des ESP32).
  * Der 3.3V-Ausgangspin des Simple FOC Mini bleibt komplett UNBESCHALTET.
  * Schalte nahe am VCC/GND-Eingang des AS5600 Encoders einen 10 µF Keramikkondensator gegen GND.

---

### 2. SIGNALVERDRAHTUNG (PIN-MAPPING)

- ESP32-C3 zu SIMPLE FOC MINI (DRV8313):
  * ESP32 GPIO 0 -> Simple FOC IN1 (PWM Phase A)
  * ESP32 GPIO 1 -> Simple FOC IN2 (PWM Phase B)
  * ESP32 GPIO 2 -> Simple FOC IN3 (PWM Phase C)
  * ESP32 GPIO 3 -> Simple FOC EN (Treiber-Aktivierung). Schalte einen 10 kΩ Widerstand als Pull-Down gegen GND (sichert, dass der Treiber beim Booten aus bleibt).
  * ESP32 GPIO 4 -> Simple FOC nFLT (Fehler-Ausgang). Schalte einen 10 kΩ Widerstand als Pull-Up gegen 3.3V.
  * Simple FOC nSLP (Sleep-Eingang) -> Über einen 10 kΩ Widerstand als Pull-Up permanent an 3.3V anschließen.
  * Simple FOC nRST (Reset-Eingang) -> Über einen 10 kΩ Widerstand als Pull-Up permanent an 3.3V anschließen.
  * Verbinde die Signal-Masse (GND) des Simple FOC Mini mit der System-GND.

- ESP32-C3 zu AS5600 ENCODER (I2C):
  * ESP32 GPIO 8 -> AS5600 SDA. Schalte einen 4.7 kΩ Widerstand als Pull-Up gegen 3.3V.
  * ESP32 GPIO 9 -> AS5600 SCL. Schalte einen 4.7 kΩ Widerstand als Pull-Up gegen 3.3V.

- ESP32-C3 zu FEETECH 1-WIRE BUS (Split-Path Level Shifter für 1 Mbps):
  Führe den UART1-Sende- und Empfangspfad auf der 3.3V-Seite getrennt und führe sie erst auf der 5V-Busseite zusammen:
  * TX-PFAD (3.3V auf 5V):
    * Verwende einen N-Channel MOSFET BSS138.
    * ESP32 GPIO 21 (UART TX) an Source des BSS138 anschließen.
    * Verbinde das Gate des BSS138 direkt mit 3.3V.
    * Verbinde den Drain des BSS138 mit der externen 5V-Feetech-Datenleitung (TTL_1_Wire).
  * RX-PFAD (5V auf 3.3V):
    * Führe das Signal von der 5V-Datenleitung (TTL_1_Wire) über einen Spannungsteiler an den ESP32 RX-Pin.
    * Schalte einen 4.7 kΩ Widerstand in Serie von der 5V-Datenleitung zu ESP32 GPIO 20 (UART RX).
    * Schalte einen 10 kΩ Widerstand von ESP32 GPIO 20 gegen GND.
  * BUS-TERMINIERUNG:
    * Schalte einen starken 2.2 kΩ Widerstand am Ausgangsstecker des Feetech-Busses als Pull-Up von der Datenleitung gegen 5V (sorgt für scharfe steigende Flanken bei 1 Mbps).

### 3. FERTIGUNGS- & LAYOUT-HINWEISE
- Platziere alle Entkopplungskondensatoren (100 nF) so nah wie physisch möglich an den VCC-Pins des jeweiligen ICs (ESP32-C3, AS5600).
- Halte die I2C-Leitungen (SDA/SCL) so kurz wie möglich und führe sie räumlich getrennt von den lauten Motor-Phasenleitungen (Phasen A, B, C) des Simple FOC Mini.
- Erstelle großflächige GND-Flächen auf Top- und Bottom-Layer für ein optimales Wärmemanagement.
```

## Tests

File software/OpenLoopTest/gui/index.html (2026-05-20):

# Smart BLDC Servo

Open-Loop Test · SimpleFOC Mini · ESP32-C3

Good Time Robotics by Emil, Anton und Andreas Pfeiffer

Verbinde...

⟳

## 📡 Live Telemetrie

Open-Loop

0 °

WINKEL (Gezielt)

0.0 U/s

DREHZAHL

Target (RPM)0

FOC DriverOK

## 🎮 Steuerung (Open-Loop)

Geschwindigkeit

Ziel-Geschwindigkeit 0 RPM

-1k-5000+500+1k

Ziehen Sie den Slider, um den Motor blind zu drehen.
Beim Loslassen stoppt der Motor sofort.

MOTOR AKTIVIEREN

SmartBLDCServo · ESP32-C3 + SimpleFOC Mini · Open-Loop Test GitHub ↗ (https://github.com/pfeifferandreas1985-create/Smart-BLDC-Servo)

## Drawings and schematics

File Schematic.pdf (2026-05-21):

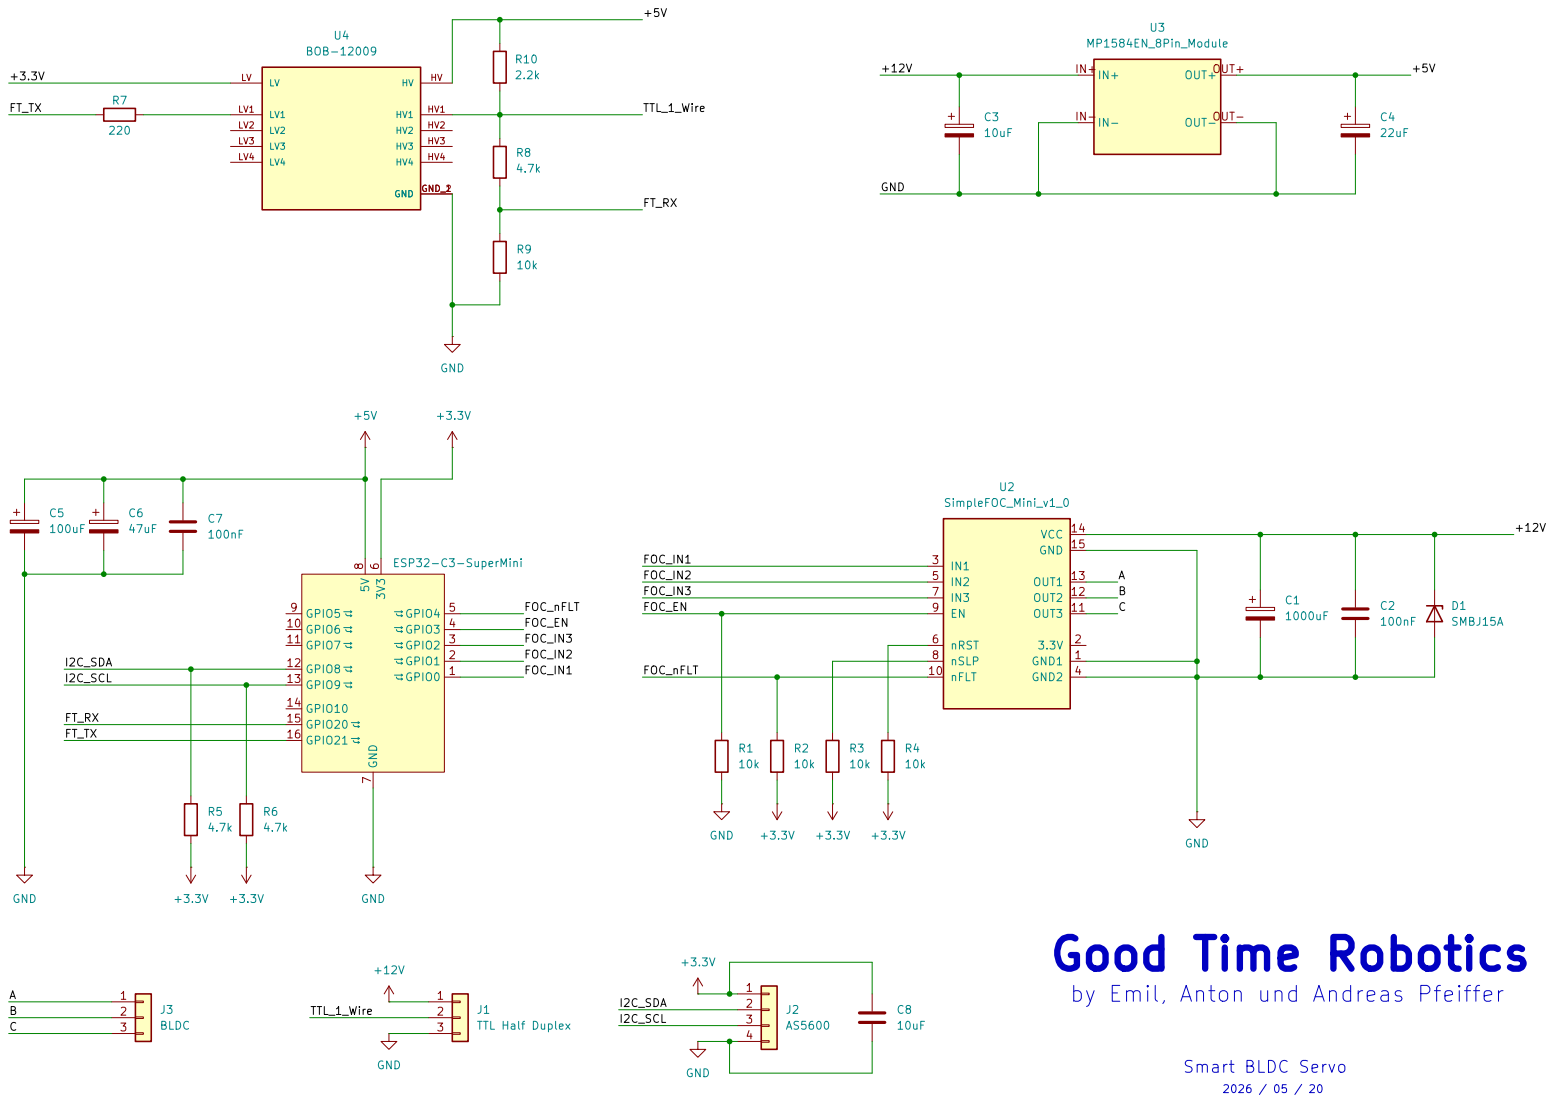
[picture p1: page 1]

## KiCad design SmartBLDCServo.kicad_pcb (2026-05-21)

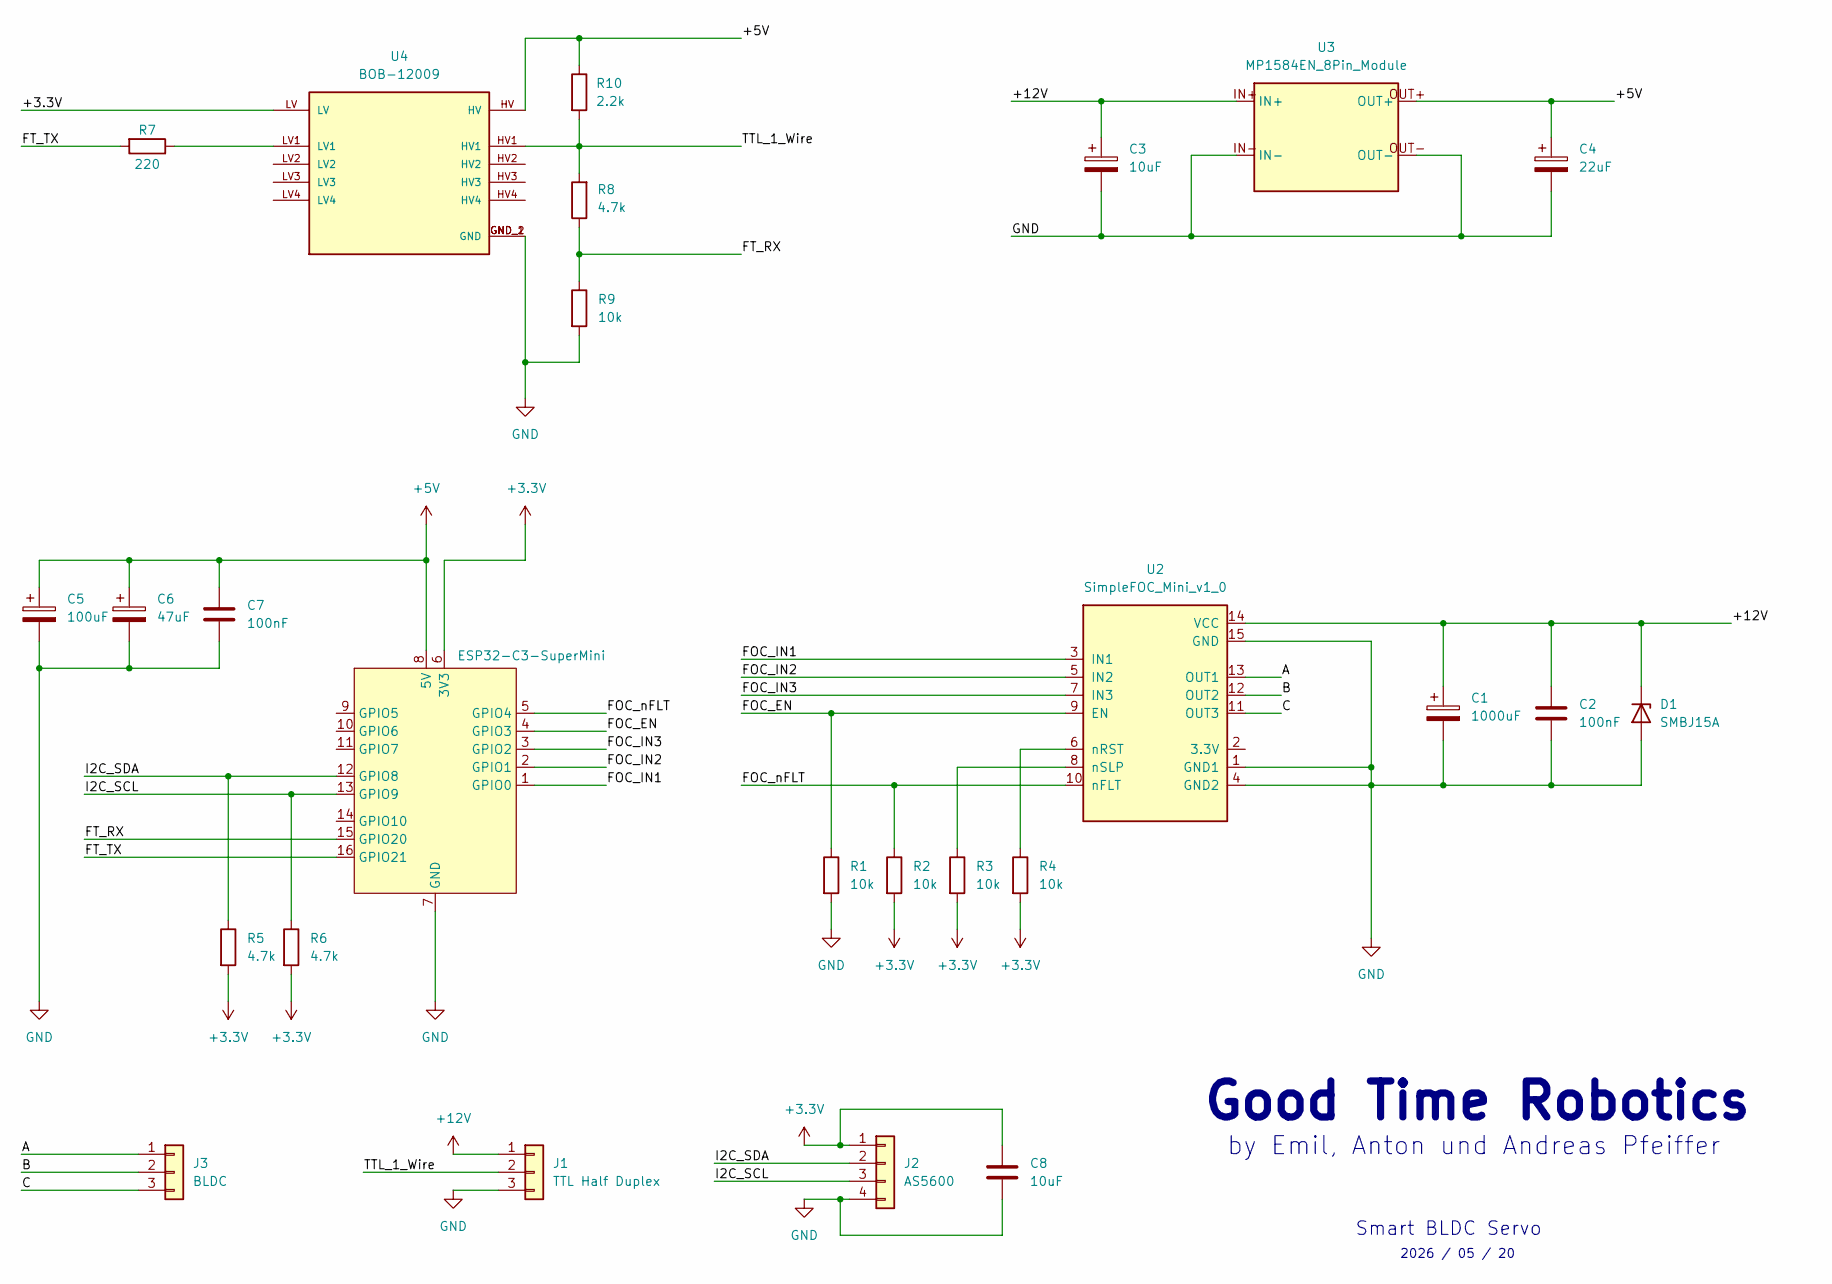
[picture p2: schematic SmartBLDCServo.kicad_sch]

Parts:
C1: 1000uF
C2, C7: 100nF; C_Disc_D3.8mm_W2.6mm_P2.50mm
C3: 10uF
C4: 22uF
C5: 100uF
C6: 47uF
C8: 10uF; CP_Radial_D6.3mm_P2.50mm
D1: SMBJ15A; D_SMB
J1: TTL Half Duplex; JST_XH_B3B-XH-A_1x03_P2.50mm_Vertical
J2: AS5600; JST_XH_B4B-XH-A_1x04_P2.50mm_Vertical
J3: BLDC; JST_XH_B3B-XH-A_1x03_P2.50mm_Vertical
R1, R2, R3, R4, R9: 10k; R_Axial_DIN0207_L6.3mm_D2.5mm_P7.62mm_Horizontal
R5, R6, R8: 4.7k; R_Axial_DIN0207_L6.3mm_D2.5mm_P7.62mm_Horizontal
R7: 220; R_Axial_DIN0207_L6.3mm_D2.5mm_P7.62mm_Horizontal
R10: 2.2k; R_Axial_DIN0207_L6.3mm_D2.5mm_P7.62mm_Horizontal
U1: ESP32-C3-SuperMini
U2: SimpleFOC_Mini_v1_0
U3: MP1584EN_8Pin_Module
U4: BOB-12009; CONV_BOB-12009; PARTREV 01

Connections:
+3.3V: C8.2, J2.1, R2.2, R3.2, R4.2, R5.2, R6.2, U1.6 (3V3), U4.LV
+5V: C4.1, C5.1, C6.1, C7.2, R10.1, U1.8 (5V), U3.OUT+, U4.HV
+12V: C1.1, C2.2, C3.1, D1.1 (K), J1.1, U2.14 (VCC), U3.IN+
/A: J3.1, U2.13 (OUT1)
/B: J3.2, U2.12 (OUT2)
/C: J3.3, U2.11 (OUT3)
/FOC_EN: R1.1, U1.4 (GPIO3), U2.9 (EN)
/FOC_IN1: U1.1 (GPIO0), U2.3 (IN1)
/FOC_IN2: U1.2 (GPIO1), U2.5 (IN2)
/FOC_IN3: U1.3 (GPIO2), U2.7 (IN3)
/FOC_nFLT: R2.1, U1.5 (GPIO4), U2.10 (nFLT)
/FT_RX: R8.1, R9.1, U1.15 (GPIO20)
/FT_TX: R7.2, U1.16 (GPIO21)
/I2C_SCL: J2.3, R6.1, U1.13 (GPIO9)
/I2C_SDA: J2.2, R5.1, U1.12 (GPIO8)
/TTL_1_Wire: J1.2, R8.2, R10.2, U4.HV1
GND: C1.2, C2.1, C3.2, C4.2, C5.2, C6.2, C7.1, C8.1, D1.2 (A), J1.3, J2.4, R1.2, R9.2, U1.7 (GND), U2.1 (GND1), U2.4 (GND2), U2.15 (GND), U3.IN-, U3.OUT-, U4.GND_1 (GND), U4.GND_2 (GND)
unnamed: R7.1, U4.LV1
unnamed: R4.1, U2.6 (nRST)
unnamed: R3.1, U2.8 (nSLP)

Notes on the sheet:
Good Time Robotics
2026 / 05 / 20
Smart BLDC Servo
by Emil, Anton und Andreas Pfeiffer

Board: 2 copper layers, 26 parts (0 on the bottom side), 20 nets, no tracks yet.

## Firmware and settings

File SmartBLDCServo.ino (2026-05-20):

#include <SimpleFOC.h>
#include <Wire.h>

// ==========================================
// PIN KONFIGURATION (ESP32-C3 Super Mini)
// ==========================================
// I2C Pins für AS5600
#define PIN_SDA 8
#define PIN_SCL 9

// Simple FOC Mini PWM Pins
#define PIN_IN1 0
#define PIN_IN2 1
#define PIN_IN3 2
#define PIN_EN  3

// Simple FOC Mini Fault Pin (nFLT)
#define PIN_nFLT 4

// UART Pins für Feetech Half-Duplex Bus (über Level Shifter)
#define PIN_RX 20
#define PIN_TX 21

// ==========================================
// MOTOR & SENSOR KONFIGURATION
// ==========================================
// Gimbal Motor 2208 80T hat typischerweise 11 Polpaare
#define POLE_PAIRS 11

// AS5600 Sensor
MagneticSensorI2C sensor = MagneticSensorI2C(AS5600_I2C);

// BLDC Driver
BLDCDriver3PWM driver = BLDCDriver3PWM(PIN_IN1, PIN_IN2, PIN_IN3, PIN_EN);

// BLDC Motor
BLDCMotor motor = BLDCMotor(POLE_PAIRS);

// ==========================================
// VARIABLEN FÜR FEETECH BUS & SCHUTZ
// ==========================================
// Target values
float target_value = 0.0;
String command_buffer = "";
unsigned long last_telemetry = 0;

// Fehlerstatus
bool driver_fault = false;
unsigned long last_fault_msg = 0;

void setup() {
  // 1. Debugging & Web-Dashboard Serial (USB)
  Serial.begin(115200);
  delay(1000);

  // 2. Schutzschaltung-Pins konfigurieren
  pinMode(PIN_nFLT, INPUT_PULLUP); // nFLT ist Open-Drain vom DRV8313

  // 3. I2C Bus initialisieren (ESP32-C3 Custom Pins)
  Wire.begin(PIN_SDA, PIN_SCL, 400000); // 400 kHz Fast Mode
  sensor.init();
  Serial.println("AS5600 Sensor initialisiert.");

  // 4. Motor & Treiber Setup
  driver.voltage_power_supply = 12.0; // 12V Netzteil
  driver.voltage_limit = 6.0;         // Max 6V an die Spulen (Gimbal Motoren haben hohen Widerstand, aber 6V ist sicher für den Anfang)
  driver.init();
  
  // Link Sensor & Driver to Motor
  motor.linkSensor(&sensor);
  motor.linkDriver(&driver);

  // 5. Control Loop Setup
  motor.voltage_sensor_align = 3.0; // 3V für das initiale Alignement
  motor.foc_modulation = FOCModulationType::SpaceVectorPWM;
  
  // PI Controller für die Position
  motor.controller = MotionControlType::angle;
  motor.P_angle.P = 20.0;
  motor.P_angle.I = 0.0;
  motor.P_angle.D = 0.5;
  motor.P_angle.output_ramp = 10000.0;
  motor.P_angle.limit = 6.0; // Max Voltage
  
  // Velocity Low Pass Filter
  motor.LPF_velocity.Tf = 0.01; // 10ms

  // Motor initialisieren & FOC kalibrieren
  Serial.println("Starte FOC Kalibrierung (Motor nicht blockieren!)...");
  motor.init();
  motor.initFOC();
  Serial.println("FOC Initialisierung abgeschlossen.");

  // 6. Feetech UART Bus (Half-Duplex) Setup
  // Wir verwenden Serial1 für die Kommunikation
  Serial1.begin(1000000, SERIAL_8N1, PIN_RX, PIN_TX);
  Serial.println("Feetech UART Bus lauscht auf 1 Mbps (Split-Path konfiguriert).");

  target_value = motor.shaft_angle;
}

void loop() {
  // 1. Hardware-Fehlerprüfung (nFLT aktiv-LOW)
  if (digitalRead(PIN_nFLT) == LOW) {
    if (!driver_fault) {
      driver_fault = true;
      motor.disable();
      driver.disable();
      Serial.println("{\"error\": \"DRIVER_FAULT\", \"msg\": \"DRIVER FAULT: Overcurrent or Overtemperature detected on SimpleFOC Mini!\"}");
    }
  }

  // 2. FOC-Berechnungen und Motorbewegung (nur wenn kein Fehler vorliegt)
  if (!driver_fault) {
    // FOC Algorithmus (muss so oft wie möglich aufgerufen werden!)
    motor.loopFOC();

    // Motor Bewegung ausführen
    motor.move(target_value);
  } else {
    // Fehlerzustand: Sende zyklisch eine Warnung alle 1 Sekunde
    if (millis() - last_fault_msg > 1000) {
      last_fault_msg = millis();
      Serial.println("{\"error\": \"DRIVER_FAULT\", \"msg\": \"STILL IN FAULT STATE. Please power cycle to reset.\"}");
    }
  }

  // 3. Telemetrie an Web-Dashboard senden (alle 100ms)
  if (millis() - last_telemetry > 100) {
    last_telemetry = millis();
    sendTelemetry();
  }

  // 4. Kommandos vom Web-Dashboard empfangen
  processDashboardCommands();

  // 5. Feetech Bus auslesen (Nicht-blockierend!)
  processFeetechBus();
}

// ==========================================
// WEB DASHBOARD KOMMUNIKATION (JSON via USB)
// ==========================================
void sendTelemetry() {
  float pos_deg = (motor.shaft_angle / (2.0 * PI)) * 360.0;
  float rpm = (motor.shaft_velocity / (2.0 * PI)) * 60.0;
  float volt = driver.voltage_power_supply;

  Serial.print("{\"pos\": ");
  Serial.print(pos_deg, 1);
  Serial.print(", \"rpm\": ");
  Serial.print(rpm, 0);
  Serial.print(", \"volt\": ");
  Serial.print(volt, 1);
  Serial.print(", \"fault\": ");
  Serial.print(driver_fault ? 1 : 0);
  Serial.println("}");
}

void processDashboardCommands() {
  while (Serial.available()) {
    char c = Serial.read();
    if (c == '\n') {
      // Wenn Fehler anliegt, können wir manuell versuchen den Fehler zurückzusetzen, 
      // falls das Board wieder abgekühlt/fehlerfrei ist.
      if (command_buffer.indexOf("\"cmd\":\"reset\"") > 0 || command_buffer.indexOf("\"cmd\": \"reset\"") > 0) {
        if (digitalRead(PIN_nFLT) == HIGH) {
          driver_fault = false;
          driver.enable();
          motor.enable();
          Serial.println("{\"info\": \"FAULT_RESET\", \"msg\": \"Fault reset successfully. Re-enabling driver.\"}");
        } else {
          Serial.println("{\"error\": \"RESET_FAILED\", \"msg\": \"Cannot reset. nFLT is still LOW (Fault active).\"}");
        }
      }

      if (!driver_fault) {
        if (command_buffer.indexOf("\"mode\":\"speed\"") > 0 || command_buffer.indexOf("\"mode\": \"speed\"") > 0) {
          motor.controller = MotionControlType::velocity;
        } else if (command_buffer.indexOf("\"mode\":\"pos\"") > 0 || command_buffer.indexOf("\"mode\": \"pos\"") > 0) {
          motor.controller = MotionControlType::angle;
        }

        int valIndex = command_buffer.indexOf("\"val\":");
        if (valIndex > 0) {
          float val = command_buffer.substring(valIndex + 6).toFloat();
          if (motor.controller == MotionControlType::velocity) {
            // Input ist U/min, Konvertierung zu rad/s
            target_value = (val / 60.0) * (2.0 * PI);
          } else {
            // Input ist Grad, Konvertierung zu rad
            target_value = (val / 360.0) * (2.0 * PI);
          }
        }

        if (command_buffer.indexOf("\"cmd\":\"zero\"") > 0 || command_buffer.indexOf("\"cmd\": \"zero\"") > 0) {
           sensor.init();
           motor.sensor_offset = sensor.getAngle();
        }
      }

      command_buffer = "";
    } else {
      command_buffer += c;
    }
  }
}

// ==========================================
// FEETECH KOMMUNIKATIONS-LOGIK (Skeleton)
// ==========================================
void processFeetechBus() {
  if (Serial1.available() >= 2) {
    while (Serial1.available()) {
      uint8_t incoming_byte = Serial1.read();
      // Skeleton placeholder for Feetech packets
    }
  }
}

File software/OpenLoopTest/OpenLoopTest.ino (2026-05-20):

#include <Arduino.h>
#include <WiFi.h>
#include <WebSocketsServer.h>
#include <ArduinoJson.h>
#include <SimpleFOC.h>

// --- PINS (ESP32-C3) ---
#define PIN_IN1 0
#define PIN_IN2 1
#define PIN_IN3 2
#define PIN_EN  3
#define PIN_nFLT 4

// --- WIFI CONFIG ---
const char* st_ssid = "FRITZ!Box 6660 Cable UE";
const char* st_pass = "28370714691864306613";
IPAddress local_ip(192, 168, 178, 78);
IPAddress gateway(192, 168, 178, 1);
IPAddress subnet(255, 255, 255, 0);

WebSocketsServer webSocket = WebSocketsServer(81);

// --- MOTOR (Open-Loop) ---
BLDCMotor motor = BLDCMotor(11);           // 11 Polpaare für Gimbal
BLDCDriver3PWM driver = BLDCDriver3PWM(PIN_IN1, PIN_IN2, PIN_IN3, PIN_EN);

float targetVelocity = 0.0;   // rad/s
bool isKilled = true;
bool driver_fault = false;

unsigned long lastTele = 0;

// --- Open-Loop Parameter (für Gimbal Motor) ---
const float OPENLOOP_VOLTAGE = 2.5;   // Start mit 2.5V (sanft, aber spürbar)
const float MAX_VELOCITY = 30.0;      // Max ~5 U/s (300 RPM) - reicht für Test

void handleWebSocket(uint8_t num, WStype_t type, uint8_t * payload, size_t length) {
    if (type == WStype_TEXT) {
        JsonDocument doc; 
        deserializeJson(doc, payload);
        
        if (doc["cmd"].is<const char*>()) {
            String cmd = doc["cmd"].as<String>();
            if (cmd == "kill") { 
                isKilled = true; 
                targetVelocity = 0;
                Serial.println("Kill command received");
            }
            else if (cmd == "enable") { 
                if (digitalRead(PIN_nFLT) == HIGH) {
                    isKilled = false; 
                    driver_fault = false;
                    Serial.println("Enable command received");
                } else {
                    Serial.println("Cannot enable - driver fault!");
                }
            }
        }
        
        if (doc["val"].is<long>()) {
            long rpm = doc["val"];
            // RPM to rad/s (Open-Loop: Begrenzung auf MAX_VELOCITY)
            float newTarget = (float(rpm) * 2.0 * PI) / 60.0;
            targetVelocity = constrain(newTarget, -MAX_VELOCITY, MAX_VELOCITY);
            Serial.print("Setpoint: ");
            Serial.print(rpm);
            Serial.println(" RPM");
        }
    }
}

void setup() {
    delay(2000);
    Serial.begin(115200);
    Serial.println("\n=== SmartBLDCServo Open-Loop Test ===");
    
    // --- HARDWARE PINS ---
    pinMode(PIN_nFLT, INPUT_PULLUP);
    
    // --- DRIVER INIT ---
    driver.voltage_power_supply = 12.0;
    driver.voltage_limit = OPENLOOP_VOLTAGE;  // Wichtig: auf 2.5V limitieren!
    driver.init();
    motor.linkDriver(&driver);
    
    // --- MOTOR OPEN-LOOP CONFIG ---
    motor.voltage_limit = OPENLOOP_VOLTAGE;
    motor.controller = MotionControlType::velocity_openloop;
    
    // Wichtige Open-Loop Parameter für Gimbal Motor
    motor.velocity_limit = MAX_VELOCITY;           // rad/s max
    motor.voltage_sensor_align = 2.0;              // Spannung für Alignment
    
    // Phase Resistance für bessere Spannungsberechnung (optional)
    motor.phase_resistance = 10.0;  // Ohm (typisch für Gimbal)
    
    motor.init();
    Serial.println("Motor initialized");
    
    // --- OPEN-LOOP ALIGNMENT (wichtig!) ---
    // Bei Open-Loop muss der Motor wissen, wo Phase A ist
    Serial.println("Performing open-loop alignment...");
    motor.zero_electric_angle = 0;  // Start mit 0
    motor.electrical_angle = 0;
    
    // Kleinen Puls geben, um den Motor zu alignen
    motor.move(2.0);  // 2 rad/s ganz langsam
    delay(1000);
    motor.move(0);
    delay(500);
    
    Serial.println("Motor ready! Send 'enable' via WebSocket to start");
    
    // Motor sicherheitshalber AUSSCHALTEN bevor WLAN verbindet!
    // Sonst zieht er konstant Strom, falls das WLAN lange braucht.
    motor.disable();
    isKilled = true;
    
    // --- WIFI ---
    WiFi.mode(WIFI_STA);
    WiFi.config(local_ip, gateway, subnet);
    WiFi.begin(st_ssid, st_pass);
    
    Serial.print("Connecting to WiFi");
    int wifi_timeout = 0;
    while (WiFi.status() != WL_CONNECTED && wifi_timeout < 20) {
        delay(500);
        Serial.print(".");
        wifi_timeout++;
    }
    
    if (WiFi.status() == WL_CONNECTED) {
        Serial.println("\nWiFi connected");
        Serial.print("IP: ");
        Serial.println(WiFi.localIP());
    } else {
        Serial.println("\nWiFi connection FAILED! Check SSID/Password.");
    }
    
    // --- WEBSOCKET ---
    webSocket.begin();
    webSocket.onEvent(handleWebSocket);
    
    Serial.println("Setup complete - waiting for commands");
}

void loop() {
    webSocket.loop();
    
    // --- HARDWARE FAULT CHECK ---
    bool fault = (digitalRead(PIN_nFLT) == LOW);
    if (fault && !driver_fault) {
        driver_fault = true;
        isKilled = true;
        targetVelocity = 0;
        motor.disable();
        Serial.println("!!! DRV8313 FAULT DETECTED !!!");
        Serial.println("Check: Overcurrent, Overtemperature, or Undervoltage");
    }
    
    // --- MOTOR CONTROL ---
    if (isKilled) {
        if (motor.enabled) {
            motor.move(0);
            motor.disable();
            Serial.println("Motor disabled (killed)");
        }
    } else {
        if (!motor.enabled) {
            motor.enable();
            Serial.println("Motor enabled - starting movement");
        }
        
        // Open-Loop move
        motor.loopFOC();
        motor.move(targetVelocity);
        
        // Kleines Debugging (alle 2 Sekunden)
        static unsigned long lastDebug = 0;
        if (millis() - lastDebug > 2000) {
            lastDebug = millis();
            float currentRPM = (motor.shaft_velocity * 60.0) / (2.0 * PI);
            Serial.print("Target: ");
            Serial.print((targetVelocity * 60.0) / (2.0 * PI));
            Serial.print(" RPM | Actual: ");
            Serial.print(currentRPM);
            Serial.print(" RPM | Voltage: ");
            Serial.println(motor.voltage.q);
        }
    }
    
    // --- TELEMETRY (alle 100ms für WebUI) ---
    if (millis() - lastTele > 100) { 
        lastTele = millis();
        JsonDocument out; 
        
        // Simulierte Position (für UI)
        static float fake_pos = 0;
        if (!isKilled && abs(targetVelocity) > 0.1) {
            fake_pos += (targetVelocity * 0.1);
            if (fake_pos > 2*PI) fake_pos -= 2*PI;
            if (fake_pos < 0) fake_pos += 2*PI;
        }
        
        out["pos"] = (fake_pos / (2*PI)) * 4096;
        out["rps"] = abs(targetVelocity / (2*PI));
        out["tmc"] = driver_fault ? "ERR" : "OK";
        out["k"] = isKilled ? 1 : 0;
        out["sp"] = (targetVelocity * 60.0) / (2.0 * PI);
        
        String json;
        serializeJson(out, json);
        webSocket.broadcastTXT(json);
    }
}

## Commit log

2026-05-14 Initial commit for Smart BLDC Servo project
2026-05-14 Add Web Serial Dashboard, JSON Telemetry, and BOM Wiring Plan
2026-05-14 Fix 220 Ohm resistor position to LV side
2026-05-20 Update hardware schematic, wiring specs, and firmware with approved protection circuits and split-path level-shifter
2026-05-20 Initialize KiCad 10.0 project cloned from stepper project, renamed to SmartBLDCServo
    [SmartBLDCServo.kicad_pcb, SmartBLDCServo.kicad_sch]
2026-05-20 Add OpenLoopTest firmware, Web GUI and update project README
    [SmartBLDCServo.kicad_sch]
2026-05-20 Update KiCad schematic with final TVS diode, capacitor, and FOC_nFLT label additions
    [SmartBLDCServo.kicad_sch]
2026-05-21 Update KiCad PCB and schematic: Fix footprint UUIDs, add SimpleFOC and MP1584EN footprints
    [SmartBLDCServo.kicad_pcb, SmartBLDCServo.kicad_sch]
2026-05-21 Add exported Schematic PDF
